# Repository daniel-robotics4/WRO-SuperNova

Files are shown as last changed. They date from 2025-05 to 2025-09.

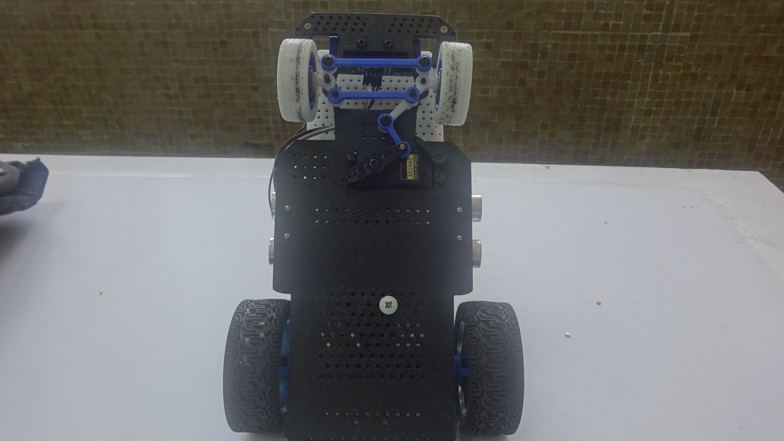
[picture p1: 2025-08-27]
v-photos/DELTA Bottom.JPG

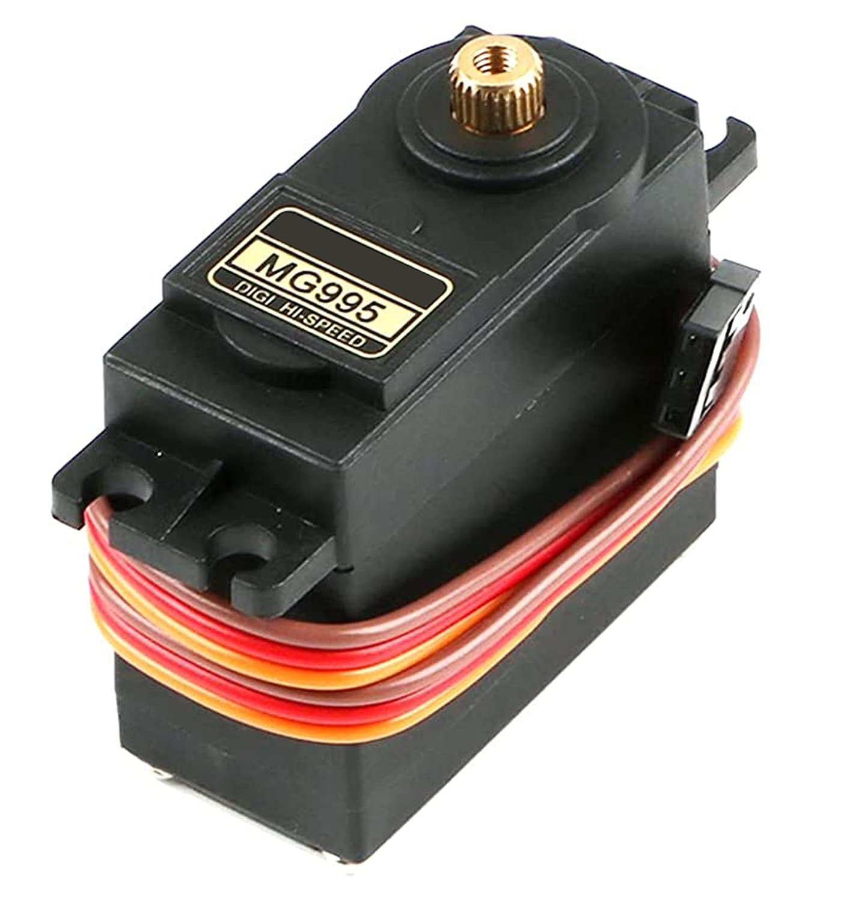
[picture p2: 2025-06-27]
other/Images of the readme/617BvnN0VJL._SL1500_.jpg

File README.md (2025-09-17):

 SuperNova 
====
supernova_final

This repository contains the documentation for the SuperNova team's robot for the 2025 World Robot Olympiad Future Engineers competition. the robot, was designed and built by a team of three students.

# Index

- [the Project](#the-project)
- [the Challenge](#the-challenge)
- [Photos of DELTA](#photos-of-delta)
- [Management](#management)
  - [Mobility Management](#mobility-management)
    - Motor DC 12v with encoder
    - Servo Motor MG995
    - Module l298n motor driver
  - [Power and Sense Management](#power-and-sense-management)
    - ESP32 DevKit v1
    - ESP32 expansion board
    - Ultrasonic sensors (hc-sr04)
    - 18650 Battery
    - Pixy Cam v2
    - Voltage regulator
- [Software/Code Documentation – CodigoDeluxe4_0.ino](#softwarecode-documentation--codigodeluxe40ino)
  - [Open challenge](#open-challenge)
    - [High-level summary](#high-level-summary)
    - [Includes and global objects](#includes-and-global-objects)
    - [Pin and constant definitions (as declared)](#pin-and-constant-definitions-as-declared)
    - [Pixy2 helper](#pixy2-helper)
    - [Ultrasonic functions](#ultrasonic-functions)
      - [filtrarUltrasonicos(NewPing &sonar)](#filtrarultrasonicosnewping--sonar)
      - [readUltrasonicSensors()](#readultrasonicsensors)
    - [Servo helper functions](#servo-helper-functions)
    - [Motor control functions](#motor-control-functions)
      - [setMotorDirection(bool forward)](#setmotordirectionbool-forward)
      - [stopMotor()](#stopmotor)
      - [MotorSpeed(bool direccion, int velocidad)](#motorspeedbool-direccion-int-velocidad)
    - [Encoder-based movement functions](#encoder-based-movement-functions)
      - [EncoderForward(int encoderTicks)](#encoderforwardint-encoderticks)
      - [EncoderBackward(int encoderTicks)](#encoderbackwardint-encoderticks)
    - [Turn routines (composed actions)](#turn-routines-composed-actions)
    - [Small correction routines](#small-correction-routines)
    - [backwardFinal()](#backwardfinal)
    - [setup()](#setup)
    - [loop() and finite-state machine (FSM)](#loop-and-finite-state-machine-fsm)
      - [START](#start)
      - [SENSE](#sense)
      - [RIGHT](#right)
      - [LEFT](#left)
      - [STRAIGHT](#straight)
      - [STOPPED](#stopped)
      - [default](#default)
    - [Variables involved in control flow](#variables-involved-in-control-flow)
    - [How the pieces interact at runtime (short narrative)](#how-the-pieces-interact-at-runtime-short-narrative)
- [Cost Report](#cost-report)
  - [Components](#components)
  - [3D Printing Costs](#3d-printing-costs)
  - [Other Parts Tested](#other-parts-tested)
  - [Tools and Equipment](#tools-and-equipment)
  - [Summary of Costs](#summary-of-costs)
- [WRO SuperNova — Complete Assembly and Wiring](#wro-supernova--complete-assembly-and-wiring)
  1. [Quick overview](#1--quick-overview)
  2. [BOM](#2--bill-of-materials)
  3. [Tools](#3--tools)
  4. [PLA printing — settings & guidance (complete)](#4--pla-printing--complete-settings--guidance)
  5. [Hole, insert & fastener strategy for PLA](#5--hole-insert--fastener-strategy-for-pla-complete)
  6. [Part-specific print & post-process notes](#6--part-specific-print--postprocess-notes)
  7. [Mechanical assembly — step-by-step](#7--mechanical-assembly--stepbystep)
  8. [Electrical wiring — pin-by-pin](#8--electrical-wiring--pin-by-pin-match-to-code)
  9. [Power, decoupling and protection](#9--power)
  10. [Software, calibration & commissioning](#10--software-calibration--commissioning)

## Contents of the repository
· `t-photos`:Includes 2 photos of the team (one official and one fun with all members). 

`v-photos`: Contains 6 photos of the vehicle (from all angles, top and bottom).  

`video` : Video.md file with link to a driving demonstration video. 

`schemes`: Schematic diagrams (JPEG, PNG or PDF) of the electromechanical components, illustrating the connection of electronic elements and motors. 

`src`: Control software code for all components programmed for the competition.

`models`: Files for models used by 3D printers, laser cutters and CNC machines to produce vehicle elements.

`other`: Additional files to understand how to prepare the vehicle for competition (SBC/SBM connection documentation, file upload, hardware specifications, etc.), old code and the images on the repository.

the Project
===
Our project consists of creating an automated land vehicle capable of navigating an environment marked by colored obstacles. the vehicle takes different paths depending on the color of the obstacle. We use an ESP32-based program (C++) that includes codes for the ultrasonic sensors (hc-sr04), which can detect objects at a predetermined distance. When an obstacle is detected, the sensors send a signal to the ESP32 circuit board, which then directs the vehicle’s movement system to turn det either clockwise or counterclockwise, as pre-established. Additionally, the vehicle is equipped with a camera module (Pixy v2) to detect colored obstacles and avoid them based on their color

the core of the system is based on the ESP32 v1 devkit microcontroller, which provides a versatile platform with sufficient input/output pins and processing capability to manage multiple sensors and actuators for basic robotics applications. the vehicle features a DC motor equipped with an encoder, allowing for precise feedback on wheel rotation to enable closed-loop speed and distance control. Four ultrasonic sensors are strategically mounted to the vehicle, giving comprehensive environmental awareness by measuring distances to obstacles in front and on both sides. A motor driver shield is used to manage power delivery and control signals to the motor, while a servomotor handles steering actuation. the chassis for this vehicle was custom-designed using 3D modeling software and subsequently fabricated with a 3D printer.

## the Challenge
Teams are challenged to create, assemble, and program a robotic car that can drive itself around a racetrack that is dynamically altered for every round. there are two primary objectives in the competition: finishing laps with randomized obstacles and pulling off a flawless parallel parking manoeuvre. Teams must incorporate cutting-edge robotics ideas with an emphasis on innovation and dependability, such as computer vision, sensor fusion, and kinematics.

This challenge emphasizes all aspects of the engineering process, including:

- Mobility Management: Developing efficient vehicle movement mechanisms.
- Obstacle Handling: Strategizing to detect and navigate traffic signs (red and green markers) within specified rules.
- Documentation: Showcasing engineering progress, design decisions, and open-source collaboration through a public GitHub repository.

## Photos of DELTA

| Front view | Back view | Left view | 
| --- |--- | --- |
| DELTA Front| DELTA Back| DELTA Left|

| Right view | Top view | Bottom view |
| --- | --- |--- |
|DELTA Right| DELTA Top |DELTA Bottom |

## Management

### Mobility Management

**Motor DC 12v with encoder:**
| Specifications: |
| ------------- |
| Voltage: 12V |
| Gear Ratio: 1:34 |
| Speed (at 12V): 126 RPM |
| Torque: 4.2 kg·cm |
| Weight: 86g |
| Encoder: Optical, 12 counts per revolution |
encoder2

the propulsion system relies on a DC motor paired with an encoder. the motor provides the mechanical force required to move the vehicle, while the encoder outputs two pulse signals (c!
hannels A and B) that indicate the rotation direction and speed by measuring the number of pulses per revolution.
We used these motors for their balance between power, efficiency, and cost, as well as their easy integration with common motor drivers like the L298N.

**Servo Motor MG995:**
| Specifications: |
| ------------- |
| Voltage: 4.8-6V |
| Torque: 9.4/11 kg/cm |
| Rotation: 180° ± 10°  |
617BvnN0VJL _SL1500_

A servomotor is integrated into the system to control steering. the servo receives PWM signals from a dedicated ESP32 pin, allowing precise angular positioning between 0° and 180°. the servo’s position is controlled programmatically to perform smooth and accurate movements.
We chose this servo for its precise position control, ease of use with Arduino libraries, and widespread availability, offering better accuracy and reliability than cheaper or less-documented servos.

**Module l298n motor driver:**
| Specifications: |
| ------------- |
| Power supply voltage: 5 to 35V  |
| Output current:  0-36mA |
| Can handle:  DC motors or stepper motors |
modulo-l298n-driver-control-motor-puente-h-arduino-0

the L298N is a robust dual H-bridge motor driver IC capable of controlling two DC motors simultaneously or one stepper motor. Each channel of the L298N can deliver up to 2A continuous current (with adequate heat dissipation) and operates within a voltage range of 5V to 35V, making it suitable for a wide range of motors.
This motor driver module interfaces easily with the ESP32 microcontroller, accepting PWM signals from the ESP32 for precise speed control and digital signals for direction control, enabling both forward and reverse movement. the L298N module also includes built-in protection mechanisms such as current sensing and thermal shutdown to safeguard the system during operation.
the L298N was selected for this project due to its ability to control two motors at once, its compatibility with the ESP32.

### Power and Sense Management

**ESP32 DevKit v1:**

|Specifications:|
| ------------ |
|Microcontroller: ESP32 |
|Flash memory: 4 Mb |
|SRAM: 520 Kb | 
|Frequency: 2.4 GHz to 2.5 GHz |
|Input voltage: 2.7 – 3.6V |
|Pins: 30 |
ModuloESP32-DEVKITV1-30pines-min_1_2048x2048

ESP32 DevKit V1:
the ESP32 DevKit V1 is a microcontroller board based on the ESP32 SoC, featuring a dual-core Tensilica processor running at up to 240 MHz. It offers integrated Wi-Fi and Bluetooth, multiple digital input/output pins, analog inputs, PWM outputs, a micro-USB connection, onboard voltage regulator, and reset/boot buttons. the ESP32 board runs the code that enables us to accomplish the challenge, processing sensor data to perform the required movements.

We selected the ESP32 DevKit V1 for its wireless connectivity, higher processing power, and compatibility with a wide range of sensors and actuators. Its user-friendly development environment, strong community support, and extensive documentation make it easier to implement complex robotics tasks compared to less-documented microcontroller boards.

**ESP32 Expansion Base board v1:**

|Specifications:|
| ------------ |
|Power supply: 5-12V|
|On-board Regulator : 5V~1A |
|SRAM: 520 Kb | 
|Frequency: 2.4 GHz to 2.5 GHz |
|Input voltage: 2.7 – 3.6V |
expansion board

the ESP32 Expansion Board V1 30P is an add-on board designed to extend the functionality of ESP32 development boards, featuring 30 accessible pins for easy connection to various peripherals. It provides organized access to multiple digital and analog inputs/outputs, power rails, and communication interfaces such as I2C, SPI, and UART. the expansion board simplifies prototyping by offering clearly labeled headers, additional power regulation options, and secure mounting for the ESP32 module, enabling robust connections for sensors, actuators, and external modules.

We selected the ESP32 Expansion Board V1 30P for its convenient pin access, stable power distribution, and compatibility with a broad range of hardware components. Its well-organized layout, ease of integration, and community support streamline the development of complex robotics solutions, making it preferable to less modular expansion boards or direct wiring, which can lead to unreliable connections and increased troubleshooting.

**Ultrasonic Sensor (hc-sr04):**
| Specifications: |
| ------------- |
| Accuracy:  ±3% |
| Measurement Range: 2 a 450 cm |
| Resolution:  0.3 cm |
| Input voltage: 5V  |
| Operating Current: 15mA |
Ultrasonic_Sensor

It is a sensor that uses ultrasonic sounds to detect the bounce time of sound from one side to the other. Using the ESP32 devkit v1 we can determine the distance based on the time it takes for the wave to return, performing the function of determining when there is a wall nearby, and thus making the corresponding turn.
This sensor was chosen for its accuracy, low cost, and readily available documentation, outperforming other more expensive or less reliable distance-sensing options.

**18650 Battery:**
| Specifications: |
| ------------- |
| Capacity: 3000 mAh |
| Voltage: 3.7 V |
| Discharge rate:  0.25C |
| Weight: 48 g (one battery) |
| Size: 18 mm diameter, 65 mm length |


we are going to use 3 of these li-ion batterys in parallel to power the vehicle, with an 18650 battery holder. This battery configuration provides a reliable and efficient power source for the robot’s electronics and actuators, supporting extended operation during competition or testing.

**PixyCam v2:**
| Specifications: |
| ------------- |
| Processor: NXP LPC4330 |
| Image sensor: Aptina MT9M114 |
| Resolution:1296×976  |
| Lens field-of-view: 80° horizontal, 40° vertical |
| Power consumption: 140mA |
| RAM: 264K bytes |
| Flash Memory: 2M bytes |
| Power input: 5V |
pixy-v21-camera-sensor

the camera is capable of detecting seven colors simultaneously and It is equipped with an internal processor, which lets us explore just the necessary information for the ESP32 to evade in the necessary way, depending on the obstacle colour.
 We selected this camera for its high-resolution image capture, easy interfacing with microcontrollers, and strong community support, providing superior performance and documentation compared to less common camera modules.

**Voltaje Regulator (Lm2596) :**
| Specifications: |
| ------------- |
| Input Voltage: 4V to 35V |
| Output Voltage:  1.23V to 37V |
| Energy eficiency : 80% |
voltage regulator

The module LM2596 is a regulator step down that can reduce de voltage of input to a lower voltage in output 

# Software/Code Documentation – `CodigoDeluxe4_0.ino`

This document describes the structure, logic, and key functions of the file: `src/CodigoDeluxe4_0.ino` in the WRO-SuperNova project.

---
# Open challenge 

## High-level summary
Firmware for an ESP32-based robot that:
- Reads four ultrasonic sensors (front, right, left, rear) using the NewPing library.
- Uses an ESP32 encoder for distance/tick measurements.
- Controls a DC motor through two direction pins and an enable pin (ENB).
- Uses a single servo for steering with three preset positions (left, center, right).
- Implements a finite-state machine to drive, sense obstacles, decide turns, execute turns using encoder distances, and count laps.

---

## Includes and global objects
- Libraries:
  - `Arduino.h`, `WiFi.h`, `Pixy2.h`, `NewPing.h`, `ESP32Encoder.h`, `ESP32Servo.h`.
- Global peripheral objects:
  - `Pixy2 pixy;`
  - `NewPing sonarRight(TRIGGER_PIN_RIGHT, ECHO_PIN_RIGHT, MAX_DISTANCE);` — right ultrasonic
  - `NewPing sonarLeft(...)` — left ultrasonic
  - `NewPing sonarFront(...)` — front ultrasonic
  - `NewPing sonarRear(...)` — rear ultrasonic
  - `Servo servo;` — steering servo
  - `ESP32Encoder encoder(true);` — encoder instance (quadrature/direction enabled)

---

## Pin and constant definitions (as declared)
- Motor:
  - DIR_PIN_A = 16
  - DIR_PIN_B = 17
  - pinENB = 5
- Ultrasonics:
  - Right: TRIGGER 33, ECHO 25
  - Left:  TRIGGER 27, ECHO 26
  - Front: TRIGGER 12, ECHO 14
  - Rear:  TRIGGER 22, ECHO 23
- Servo pin: 2
- Distances, thresholds and tuning variables:
  - MAX_DISTANCE = 300
  - servoL = 115, servoC = 80, servoR = 50
  - frontObject = 90
  - cantMuestras = 5 (samples per ultrasonic sensor read)
  - DELAY_ULTRASONICOS = 10 (ms)
  - wallfence = 20
  - laps = 0
  - sense = 0 (direction chosen during sensing: 1 or 2)
  - maximumCorrections = 0

---

## Pixy2 helper
- `getSignatureColorName(int signature)`
  - Returns a human-readable name for a Pixy signature id.
  - Cases: `1 -> "Verde"`, `2 -> "Rojo"`, default -> `"Desconocido"`.
- (There are commented-out helper functions that format Pixy block data as HTML; they call `pixy.ccc.getBlocks()` and iterate `pixy.ccc.blocks` to extract signature, x/y/width/height.)

---

## Ultrasonic functions

### filtrarUltrasonicos(NewPing &sonar)
- Purpose: take multiple readings from a single NewPing sonar and return a filtered average distance in cm.
- Behavior:
  - Performs `cantMuestras` readings using `sonar.ping_cm()`.
  - Treats `0` returned by `ping_cm()` as `MAX_DISTANCE`.
  - Keeps running `sum`, tracks `minVal` and `maxVal`, and counts samples (`validCount`).
  - After sampling, subtracts `minVal` and `maxVal` from `sum` (trim one min and one max) and divides by `validCount - 2` (if `validCount >= 3`) or `validCount` otherwise.
  - Returns the computed average as `unsigned int`.
- Notes on outputs: returns a value in cm bounded by `MAX_DISTANCE`.

### readUltrasonicSensors()
- Purpose: update global distances for all four ultrasonic sensors.
- Behavior: calls `filtrarUltrasonicos()` for each sonar and stores results in:
  - `distanceFront`, `distanceRight`, `distanceLeft`, `distanceRear`.
- After reading, any zero distances are set to `MAX_DISTANCE` (safeguard).

---

## Servo helper functions
- `servoRigth()` — write servo angle `servoR` (steer right) and short `delay(15)`.
- `servoLeft()` — write servo angle `servoL` (steer left) and short `delay(15)`.
- `servoCenter()` — write servo angle `servoC` (center steering) and short `delay(15)`.

These functions position the steering servo to one of three predefined angles.

---

## Motor control functions

### setMotorDirection(bool forward)
- Sets motor direction pins for forward or backward motion:
  - If `forward == true`: DIR_PIN_A = LOW, DIR_PIN_B = HIGH.
  - Else: DIR_PIN_A = HIGH, DIR_PIN_B = LOW.

### stopMotor()
- Stops the motor by setting DIR_PIN_A = LOW, DIR_PIN_B = LOW and pinENB = LOW.

### MotorSpeed(bool direccion, int velocidad)
- Calls `setMotorDirection(direccion)` to choose direction.
- Writes `velocidad` to `pinENB` using `digitalWrite(pinENB, velocidad)`.
- Intended to control motor speed and direction together.

---

## Encoder-based movement functions

### EncoderForward(int encoderTicks)
- Purpose: move forward until the encoder count reaches `encoderTicks`.
- Behavior:
  - Calls `encoder.clearCount()` to reset the encoder count.
  - While `encoder.getCount() < encoderTicks`:
    - Calls `MotorSpeed(true, 150)` to move forward.
    - Delays 10 ms inside loop.
  - Calls `stopMotor()` and `encoder.clearCount()` at the end.

### EncoderBackward(int encoderTicks)
- Purpose: move backward until the encoder count goes beyond `encoderTicks`.
- Behavior:
  - Calls `encoder.clearCount()`.
  - While `encoder.getCount() > encoderTicks`:
    - Calls `MotorSpeed(false, 150)` to move backward.
    - Delays 10 ms inside loop.
  - Calls `stopMotor()` and `encoder.clearCount()` at the end.

Notes:
- These functions use the encoder reading to control distances moved by repeated on/off motor commands until the encoder target is reached.

---

## Turn routines (composed actions)
Each routine uses the encoder move functions and servo to perform a turn maneuver.

- `Lbig()`:
  - Calls `EncoderBackward(-700)` (back up),
  - Calls `servoLeft()` (steer left),
  - Calls `EncoderForward(1300)` (move forward the turn distance),
  - Calls `servoCenter()` (re-center).

- `Lsmall()`:
  - Calls `EncoderBackward(-650)`,
  - `servoLeft()`,
  - `EncoderForward(1300)`,
  - `servoCenter()`.

- `Rbig()`:
  - Calls `EncoderBackward(-700)`,
  - `servoRigth()` (steer right),
  - `EncoderForward(1300)`,
  - `servoCenter()`.

- `Rsmall()`:
  - Calls `EncoderBackward(-650)`,
  - `servoRigth()`,
  - `EncoderForward(1300)`,
  - `servoCenter()`.

These routines perform: back up slightly, set steering to turn direction, move forward a fixed encoder distance to complete the turn, then re-center the servo.

---

## Small correction routines
- `correctionL()`:
  - Set servo to left,
  - Call `MotorSpeed(true, 120)` to move forward briefly,
  - `delay(200)`,
  - `servoCenter()` and `delay(15)`.

- `correctionR()`:
  - Set servo to right,
  - `MotorSpeed(true, 120)`,
  - `delay(200)`,
  - `servoCenter()` and `delay(15)`.

These move the robot slightly forward while steering to perform small lateral corrections.

---

## backwardFinal()
- Calls `Lbig()` if `sense == 1`.
- Calls `Rbig()` if `sense == 2`.
- Used as a final backup-and-turn routine when stopping.

---

## setup()
- Initializes Serial at 115200.
- Configures motor pins DIR_PIN_A, DIR_PIN_B, pinENB as OUTPUT.
- Attaches servo on `servoPin` with pulse width range 500–2500 µs.
- Initializes Pixy2: `pixy.init()`.
- Configures encoder:
  - Enables internal pull-ups: `ESP32Encoder::useInternalWeakPullResistors = puType::up`.
  - Attaches encoder pins with `encoder.attachSingleEdge(4, 5)`.
  - Clears encoder count `encoder.clearCount()`.
- Initializes `lastStateChangeTime = millis()` (used for potential state timing).

---

## loop() and finite-state machine (FSM)
`loop()` repeatedly:
- Calls `readUltrasonicSensors()` to update distanceFront, distanceLeft, distanceRight, distanceRear.
- Updates `encoderTicks = encoder.getCount()`.
- Uses `switch(currentState)` to run the FSM. States:

### START
- Centers the servo.
- Reads ultrasonic sensors.
- Sets `sense = 0`.
- Calls `MotorSpeed(true, 200)` to move forward.
- If `distanceFront < frontObject` and `distanceFront != MAX_DISTANCE` and `sense == 0`:
  - Calls `stopMotor()`.
  - Sets `currentState = SENSE`.

### SENSE
- Decides turning direction by comparing lateral distances:
  - If `distanceLeft < distanceRight`:
    - Sets `sense = 2` (right) and `currentState = RIGHT`.
  - If `distanceRight < distanceLeft`:
    - Sets `sense = 1` (left) and `currentState = LEFT`.

### RIGHT
- If `laps < 11`:
  - If `distanceLeft < 70` and `distanceLeft > 0`:
    - `laps += 1; Rbig(); readUltrasonicSensors(); maximumCorrections = 0; currentState = STRAIGHT;`
  - Else if `70 < distanceLeft < 100`:
    - `laps += 1; Rsmall(); readUltrasonicSensors(); maximumCorrections = 0; currentState = STRAIGHT;`
- Else if `laps >= 11`:
  - `currentState = STOPPED`.

### LEFT
- Symmetric behavior to RIGHT but uses `distanceRight` for decisions:
  - If `distanceRight < 70` and `distanceRight > 0` => `Lbig()` etc.
  - If `70 < distanceRight < 100` => `Lsmall()` etc.
  - If `laps >= 11` => `currentState = STOPPED`.

### STRAIGHT
- Calls `MotorSpeed(true, 70)` to drive forward at a slower speed.
- Calls `readUltrasonicSensors()` then:
  - If `distanceFront < frontObject` and `sense == 1` and `distanceFront > 50`:
    - `currentState = LEFT`.
  - If `distanceFront < frontObject` and `sense == 2` and `distanceFront > 50`:
    - `currentState = RIGHT`.
  - If `distanceFront < 10`:
    - Decrements `laps`, moves backward for a short fixed time (`MotorSpeed(false, 200)` + `delay(1500)`), then stops motor.
- Lateral corrections within STRAIGHT:
  - If `distanceLeft < wallfence` and `maximumCorrections < 2`: increment `maximumCorrections` and call `correctionR()`.
  - If `distanceRight < wallfence` and `maximumCorrections < 2`: increment `maximumCorrections` and call `correctionL()`.

### STOPPED
- Calls `backwardFinal()` (final backup & turn depending on `sense`).
- Calls `stopMotor()`.
- `delay(50000)` to remain stopped for a period.

### default
- Sets `currentState = STRAIGHT`.

---

## Variables involved in control flow
- `currentState` (enum CarState): `START`, `STOPPED`, `SENSE`, `RIGHT`, `LEFT`, `STRAIGHT`.
- `sense`: direction decision (1 = left, 2 = right, 0 = none).
- `laps`: increments each time a corner/turn is executed; used to limit runs.
- `maximumCorrections`: counter for lateral corrections applied while moving straight.

---

## How the pieces interact at runtime (short narrative)
- The robot begins in `START`, moves forward, and monitors the front ultrasonic sensor.
- When an obstacle is detected within `frontObject`, it transitions to `SENSE` and compares left/right distances to choose a turn direction (`sense`).
- It executes the chosen turn (big or small) using encoder-based forward/backward moves combined with steering via servo.
- After turning it enters `STRAIGHT` to follow the corridor, apply lateral corrections, and watch for the next obstacle to repeat the cycle.
- `laps` is incremented on each corner; when a target number of laps is reached the FSM transitions to `STOPPED` and performs a final backup-and-turn before stopping.

---

# Close challenge 

## 1 — High-level summary
This sketch runs on an ESP32 and coordinates a Pixy2 camera, four ultrasonic sensors (NewPing), a steering servo, an encoder, and a DC motor controlled by an H-bridge. The program implements a finite-state machine to search for colored blocks (green/red) using Pixy2 and execute preprogrammed maneuvers when colors are detected.

Main flow: START → WALL → SEARCH → (GREEN or RED) → back to SEARCH or WALL. Flags `G` and `R` remember whether a maneuver for green or red has already been executed.

---

## 2 — Pin mapping
- Motor:
  - DIR_PIN_A = GPIO16
  - DIR_PIN_B = GPIO17
  - pinENB = GPIO32 (H-bridge enable / speed)
- Servo:
  - servoPin = GPIO2
- Ultrasonic sensors (NewPing):
  - Right TRIG / ECHO = GPIO33 / GPIO25
  - Left TRIG / ECHO = GPIO27 / GPIO26
  - Front TRIG / ECHO = GPIO13 / GPIO14
  - Rear TRIG / ECHO = GPIO21 / GPIO34
- Encoder:
  - encoder.attachSingleEdge(4, 22) → channel A GPIO4, channel B GPIO22
- Pixy2:
  - object `pixy` used; blocks retrieved with `pixy.ccc.getBlocks()` and read via `pixy.ccc.blocks[]`

---

## 3 — Key variables and constants
- Servo angles: `servoL = 115`, `servoC = 80`, `servoR = 50`
- Ultrasonic parameters:
  - `MAX_DISTANCE = 300` cm
  - `cantMuestras = 5` samples per sensor
  - `DELAY_ULTRASONICOS = 10` ms between pings
  - `wallfence = 30` cm (distance considered "close" to a wall)
  - `frontObject = 90` (front threshold referenced in other sketches)
- Motion/encoder:
  - `ppr = 1400` pulses per revolution (not directly used here)
  - `laps`, `diameter` (context variables, not central here)
- Color flags:
  - `G` and `R` are 0/1 flags tracking green/red maneuvers
- `sense` determines preferred turn direction during the WALL routine
- `pixy.ccc.numBlocks` contains the number of color blocks detected by Pixy

---

## 4 — Main objects
- `Pixy2 pixy` — camera block detection (color signatures)
- `NewPing sonarRight/Left/Front/Rear` — ultrasonic sensors
- `ESP32Encoder encoder(true)` — quadrature encoder counter
- `Servo servo` — steering servo

---

## 5 — Important functions (what they do)

### filtrarUltrasonicos(NewPing &sonar)
- Takes `cantMuestras` readings with `sonar.ping_cm()`.
- Replaces 0 with `MAX_DISTANCE`.
- Sums values, discards min and max (if enough samples), and returns the averaged result.
- Purpose: reduce spurious readings / outliers.

### readUltrasonicSensors()
- Calls `filtrarUltrasonicos()` for each sensor and sets `distanceFront/Right/Left/Rear`.
- Ensures that a returned 0 is converted to `MAX_DISTANCE`.

### servoRight(), servoLeft(), servoCenter()
- Move the servo to preconfigured angles and wait 15 ms.

### setMotorDirection(bool forward), stopMotor(), MotorSpeed(bool direccion, int velocidad)
- `setMotorDirection` sets DIR pins for forward/backward.
- `stopMotor` sets both DIR pins LOW and `pinENB` LOW.
- `MotorSpeed` sets direction and calls `analogWrite(pinENB, velocidad)` to control speed.
  - Note: `analogWrite` is not the standard Arduino API on the ESP32 core — LEDC (ledcSetup/ledcAttachPin/ledcWrite) is recommended.

### EncoderForward(int encoderTicks), EncoderBackward(int encoderTicks)
- Clear encoder count, then loop while encoder count hasn't reached target, commanding MotorSpeed inside the loop and delaying.
- After reaching target, call stopMotor() and clear encoder count.
- These functions are blocking and currently have no timeout safeguards.

---

## 6 — State machine (detailed)

### START
- Centers servo, sets `sense = 1`, and transitions to `WALL`.
- Acts as a simple initialization step and chooses a default turning sense (right).

### WALL
- Moves forward with `MotorSpeed(true, 200)` for 2 seconds, then stops.
- Based on `sense`:
  - If `sense == 1`: steer right, reverse for 2 seconds, center servo, `EncoderForward(300)`, go to `SEARCH`.
  - If `sense == 2`: same but mirrored (left).
- Purpose: reposition the robot away from a wall and get into a search posture.
- Note: there is commented code that would choose `sense` based on left vs right distances; currently `sense` is forced in START.

### SEARCH
- Iterates over `pixy.ccc.numBlocks` and:
  - If `m_signature == 1` → set state to `GREEN`.
  - If `m_signature == 2` → set state to `RED`.
  - Else (inside the for) it calls `MotorSpeed(true, 200)` and delays 200 ms.
- Issue: If `pixy.ccc.numBlocks == 0`, the for-loop does not run and the robot will not advance. The intended behavior probably is: if no blocks detected, advance; otherwise process blocks. The current placement of MotorSpeed inside the `else` of the for is problematic.

### GREEN
- Behavior depends on flags `R` and `G`:
  - If `R == 1`: sequence Left → forward 400, Right → forward 900, Center → forward 100; set `G = 0`, return to `SEARCH`.
  - If `(G == 0) && (R == 0)`: Left → forward 700, Right → forward 700, Center → forward 100; set `G = 1`, return to `SEARCH`.
  - Else if `G == 1`: move slowly `MotorSpeed(true, 30)`; if `distanceFront < 20` → set `G = 0`, go to `WALL`.
- Purpose: first detection triggers a larger exploratory maneuver (marking `G = 1`), subsequent detections switch to slow advance until a frontal obstacle is detected.

### RED
- Symmetric to GREEN but using the `R` flag:
  - If `G == 1`: perform a maneuver, clear `G = 0`, return to `SEARCH`.
  - If `(R == 0) && (G == 0)`: perform a maneuver, set `R = 1`, return to `SEARCH`.
  - If `R == 1`: move slowly; if `distanceFront < 20` then `R = 0`, transition to `WALL`.

### STOPPED
- Present in the enum but not used.

---

---

# Cost Report
## Components
Component	Quantity	Cost per Unit ($)	Total ($)
| Componets | Component	Quantity  | Cost per Unit ($) | Total ($) |
| --- | --- |--- |--- |
| Motor DC GS20179-09 | 1 | 20.79 | 20.79 |
| Servo Motor MG995 | 1 | 3.71 | 3.71 |
| Module l298n motor driver | 1 | 4.99 | 4.99 |
| ESP32 DevKit v1 | 1 | 15.99 | 15.99 |
| ESP32 expansion board | 9.99 | 9.99 |
| Ultrasonic sensors (hc-sr04) | 4 | 4.99 | 15.96 |
| EBL 18650 Battery 3.7v 3300mha | 3 | 5.49 | 16.47 |
| PixyCam v2 | 1 | 69.90 | 69.90 | 
| Voltaje Regulator (Lm2596) | 1 | 4.52 | 4.52 | 
| Wheels of 2.559 | 2 | 4.99 | 9.98 | 
| 18650 3 battery holder | 1 | 1.99 | 1.99 |
| DuPont cable jumper | 1 kit | 7.99 | 7.99 |

**Total for Components: 182.28$**

## 3D Printing Costs
Filament Used:
Prototypes: 1.5 kg of PLA filament
Final Parts: 250g of PLA filament
PLA Filament Cost: 25.00 $  per 1kg
| Filament Use | Weight (g)	| Cost ($) |
| --- | --- | --- |
| Prototypes | 1,500 | 45.00 | 
| Final Parts	| 250 | 7.45 |

**Total for 3D Printing: 52.45$**

## Other Parts Tested
**Approximate Cost for Additional Parts Tested: 472.00$**
## Tools and Equipment
| Tool | Cost ($) |
| ---- | ---|
| Bambu Lab A1 mini 3D Printer | 299.00 |
| Soldering iron | 11.99 |
| Multimeter | 18.00 |
| Miscellaneous Tools | 39.00 |

**Total for Tools and Equipment: 367.00$**

## Summary of Costs
| Category | Total ($) | 
| --- | --- |
| Components | 174.29 |
| 3D Printing | 52.45 |
| Other Parts Tested | 472.00 |
| Tools and Equipment | 367.00 |
| Shipping Approximation | 10.00 |

**Grand Total: 1.082,99$**

*Note: Costs are approximate and based on current exchange rates and market prices.*

# WRO SuperNova — Complete Assembly and Wiring

This is the single, canonical assembly guide for DELTA. It covers everything from printing settings to mechanical assembly, wiring to the corrected firmware (ENB → GPIO13 PWM), safety, commissioning and troubleshooting — all in one place so you can follow it end-to-end.

Use the repo images for reference during assembly:
- other/Images of the readme/ModuloESP32-DEVKITV1-30pines-min_1_2048x2048.jpg
- other/Images of the readme/Base expansora para ESP32.jpg
- other/Images of the readme/Ultrasonic_Sensor.jpg
- other/Images of the readme/pixy-v21-camera-sensor.jpg
- other/Images of the readme/voltage regulator.jpg
- v-photos/ The DELTA photos for mechanical orientation
- schemes/ use the schemes for cable orientation 

Repository firmware this guide matches:
- CodigoDeluxe4_1.ino

---

Table of contents
1. Quick overview
2. BOM 
3. Tools
4. PLA printing — settings & guidance (complete)
5. Hole, insert & fastener strategy for PLA
6. Part-specific print & post‑process notes
7. Mechanical assembly — step‑by‑step (with wiring cues)
8. Electrical wiring — pin-by-pin
9. Power, decoupling and protection
10. Software, calibration & commissioning

---

1 — Quick overview
This guide assumes you will print almost all robot mechanical parts in PLA. PLA works well: good dimensional accuracy, stiff parts, and easy printing. This guide addresses PLA limitations (heat sensitivity, reduced screw-hold longevity) and gives methods to make a reliable robot while staying .

Firmware/pin reference:
- Motor DIR A → GPIO16
- Motor DIR B → GPIO17
- Motor EN (PWM) → GPIO13 
- Servo signal → GPIO2 (MG995)
- Encoder A/B → GPIO4 / GPIO5
- Ultrasonics:
  - Front TRIG/ECHO → GPIO12 / GPIO14
  - Right TRIG/ECHO → GPIO33 / GPIO25
  - Left TRIG/ECHO → GPIO27 / GPIO26
  - Rear TRIG/ECHO → GPIO22 / GPIO23
- Pixy2 → SPI recommended (3.3V Vcc); connect per Pixy docs

---

2 — Bill of Materials 
Mechanical
- Robot CarDC V4 chasis .stl — bottom chassis
- Chasis superior V2.stl — top cover
- Direccionales Robot Chasis V4.stl — steering mounts / knuckles
- MG995.stl (horn/bracket) or use the servo-supplied horn
- Ruedas V2.stl

Electronics
- ESP32 DevKit (30-pin)
- Motor driver L298n
- expansion board v1 for ESP32
- DC motor with encoder and wheels
- MG995 or similar servo
- Pixy2 camera module
- 4 × HC-SR04 ultrasonic sensors 
- Power: 18650 3000mh x3
- Wiring: DuPont jumper wires
  
Consumables & fasteners
- M3 machine screws (assorted lengths) + M3 nuts
- Zip‑ties, foam tape, cable clips

---

3 — Tools
- 3D printer (FDM) configured for PLA
- Small screwdriver set (PH0/PH1), hex keys
- Soldering iron + shrink tubing
- Multimeter
- Wire stripper/crimper, pliers
- Drill or reamer (3.0–3.2 mm) for hole finishing
- Heat gun/hot air or soldering iron for low-temp insert installation (use with care)
- Calipers for dimensional checks

---

4 — PLA printing — complete settings & guidance

Printer nozzle & bed
- Nozzle: 0.4 mm
- Bed: PEI, glass or taped bed works fine
- Nozzle temp: 200–210 °C (start 205 °C; tune by filament)
- Bed temp: 55–60 °C
- Fan: 100% after first 2–3 layers

Layer & perimeters
- Layer height: 0.16–0.20 mm (0.12 mm for small high-detail pivots)
- Perimeters: 3–4 (4 recommended for chassis and load zones)
- Top/bottom layers: 6

Infill
- Chassis & load-bearing parts: 35–40% gyroid or grid
- Brackets/covers: 15–25%
- Pivot/knuckle areas: 30–40%

Speeds & retraction
- Print speed: 40–50 mm/s
- Perimeter speed: 30–40 mm/s for stronger walls
- Retraction: Bowden 4–6 mm / Direct 0.8–1.2 mm; retraction speed 25–40 mm/s

Adhesion & supports
- Brim: 3–8 mm for large chassis parts
- Supports: tree supports for overhangs; minimize contact with cosmetic surfaces
- First layer: 20–25 mm/s, slightly higher extrusion multiplier if needed

Slicer tuning tips
- Use 4 perimeters for screw bosses; enable “pause after layer” if you want to embed nuts mid-print.
- Turn on “Z hop” only if needed; it can reduce small scuffs.
- Enable “coast at end” and “retraction in wipe” if stringing appears.

Cooling & warping
- PLA benefits from active cooling; ensure 100% fan once layers are stable.
- For long prints, avoid drafts or sudden ambient temp changes.

---

5 — Hole, insert & fastener strategy for PLA (complete)

PLA characteristics
- Stiff and dimensionally accurate, but more brittle and less heat-resistant than PETG.
- Repeated screwing into raw PLA will wear threads.

Recommended fastening approaches

Hole prep
- Print holes slightly undersized.
- Ream or drill to 3.0–3.2 mm for M3 clearance if using machine screws with nuts.
- For screws threading into PLA, pilot holes 2.6–2.8 mm are good for M3 self-tapping screws.

---

6 — Part-specific print & post‑process notes

A) Main chassis — Robot CarDC V4 chasis .stl
- Orientation: flat on the bed — largest surface down.
- Settings: 0.16–0.20 mm layer, 4 perimeters, 40% infill, brim 5–8 mm.
- Post: ream screw holes, remove any internal supports, chamfer screw entry slightly for easier insertion.

B) Top layer — Chasis superior V2.stl
- Orientation: as modeled for correct standoffs up.
- Settings: 0.16–0.20 mm layer, 3 perimeters, 20% infill.
- Post: test-fit standoffs and ESP32/devkit.

C) Direccionales (steering) — Direccionales Robot Chasis V4.stl
- Orientation: pivot holes vertical (hole axis along Z) for best circularity.
- Settings: 0.12–0.16 mm layer for pivot detail, 4 perimeters around pivots, 30% infill.
- Post: sand pivot bores lightly; test-fit bearings/bushings.

D) Servo horn & bracket — MG995.stl
- Orientation: horn flat on bed.
- Settings: 0.12–0.16 mm layer, 4 perimeters, 30% infill.
- Post: test fit on servo spline; if tight, sand minimal.

---

7 — Mechanical assembly — step‑by‑step

Preparation (before fastening)
- Clean all prints, deburr, ream holes as needed, and gather hardware and electronics.
- Label wires (TRIG/ECHO, motor, servo) with tape for easy routing.

Assembly Steps
1) Install the motor into bottom chassis
   - Mount motor in motor mount provided; use M3 screws with nuts. Keep motor wire exit toward the side for short routing, add the smaller gear into the motor.

2) Mount wheel hubs and steering module
   - Place the inside bearing, then the bar and the bigger gear and the outside bearing, mount the wheels and the use the bottom photo of delta fro better guidance for the steering module

3) Mount motor driver 
   - Place motor driver close to motor to minimize VMOT wiring.

4) Mount ESP32 DevKit
   - Place ESP32 on the expansion board/expansion hat in the designated place in the top layer.
   - Secure with M2.5/M3 screws and nuts; use a captive nut if possible.

5) Mount servo (MG995)
   - Place servo in its bracket, secure with M3 screws.
   - Attach horn matching steering arm and center servo before final tightening.

6) Install ultrasonic sensors
   - Insert HC‑SR04 modules into their cutouts with front facing outward.
   - Secure with screws or double-sided tape; ensure sensor face is unobstructed.

7) Mount Pixy2 camera
   - Attach Pixy2 on front bracket; route its cable toward the ESP32 hat area.
   - the Pixy needs a designated regulator for the 5V

8) Connect encoder wires
   - Route encoder A/B to GPIO4/GPIO5; keep wires short and twisted.

9) Connect servo and sensors
   - Route servo signal to GPIO2; servo Vcc to dedicated 5–6V supply (do not power servo from weak 5V regulators).

10) Place top layer & fasten
   - attach the top layer, secure with screws (.

11) Cable routing & strain relief
   - Use zip ties; ensure no wires touch moving parts.
   - Keep high-current motor wires separate from sensor wires.

---

8 — Electrical wiring — pin-by-pin (match to code)

Pin mapping:
- Motor DIR A (IN1) ← GPIO16
- Motor DIR B (IN2) ← GPIO17
- Motor EN (PWM ENB) ← GPIO13 (LEDC ch0)
- Servo signal ← GPIO2 (MG995)
- Encoder A ← GPIO4
- Encoder B ← GPIO5
- HC-SR04 Front: TRIG → GPIO12, ECHO → GPIO14 (ECHO level-shifted)
- HC-SR04 Right: TRIG → GPIO33, ECHO → GPIO25 (ECHO level-shifted)
- HC-SR04 Left: TRIG → GPIO27, ECHO → GPIO26 (ECHO level-shifted)
- HC-SR04 Rear: TRIG → GPIO22, ECHO → GPIO23 (ECHO level-shifted)
- Pixy2: SPI recommended (MOSI/MISO/SCK/CS) — Pixy Vcc → 3.3V, GND → common GND

Wiring rules
- All grounds must be common: ESP32 GND, motor driver GND, servo GND, sensor GND.
- Use JST connectors for sensors & servo where practical to make removal easy.

Motor driver wiring
- VMOT (+) ← motor battery positive 
- VMOT GND ← motor battery negative
- IN1 ← GPIO16; IN2 ← GPIO17; EN ← GPIO13 (PWM)
- OUTA/OUTB ← motor terminals

---

9 — Power

Power rails
- 3 3.7v 18650 batteries in parallel going to each regulator for its designated components 

---

10 — Software, calibration & commissioning

Firmware
- Use the provided `CodigoDeluxe4_1.ino`.
- Ensure you uploaded the corrected sketch (ENB on GPIO13).

Note: To upload code from the Arduino IDE to an ESP32, first ensure the ESP32 board package is installed via the Boards Manager within the Arduino IDE.
 Select the correct ESP32 board model from the Tools > Board menu and choose the appropriate COM port under Tools > Port.
 For boards that do not enter flashing mode automatically, press and hold the BOOT button on the ESP32 while clicking the Upload button in the Arduino IDE; release the BOOT button once the upload process starts.
 If the upload fails with a timeout error, try pressing the on-board RST or EN button when the IDE shows "Connecting..." in the output console.
 After a successful upload, press the EN button to restart the ESP32 and run the new code.

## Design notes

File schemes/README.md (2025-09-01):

Electromechanical diagrams
====

DELTA Final electric diagram

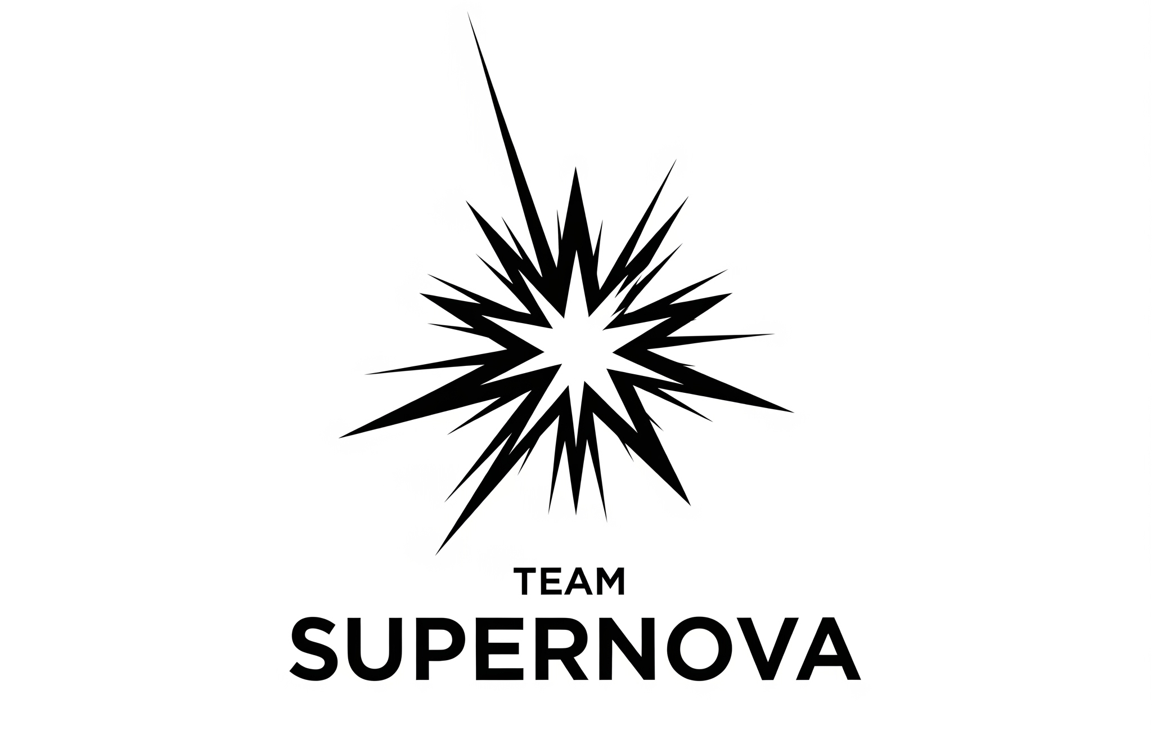
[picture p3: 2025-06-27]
other/Images of the readme/supernova_final.png

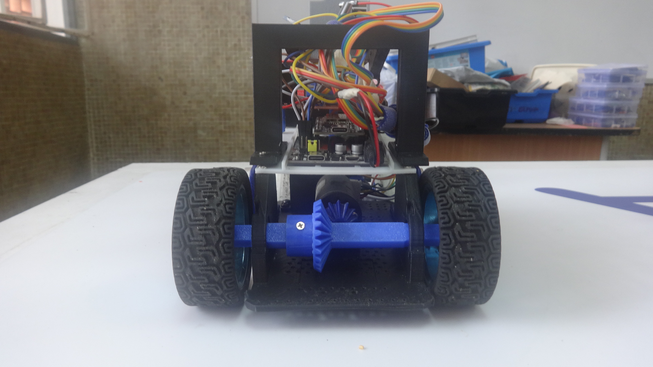
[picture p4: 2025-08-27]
v-photos/DELTA Back.JPG

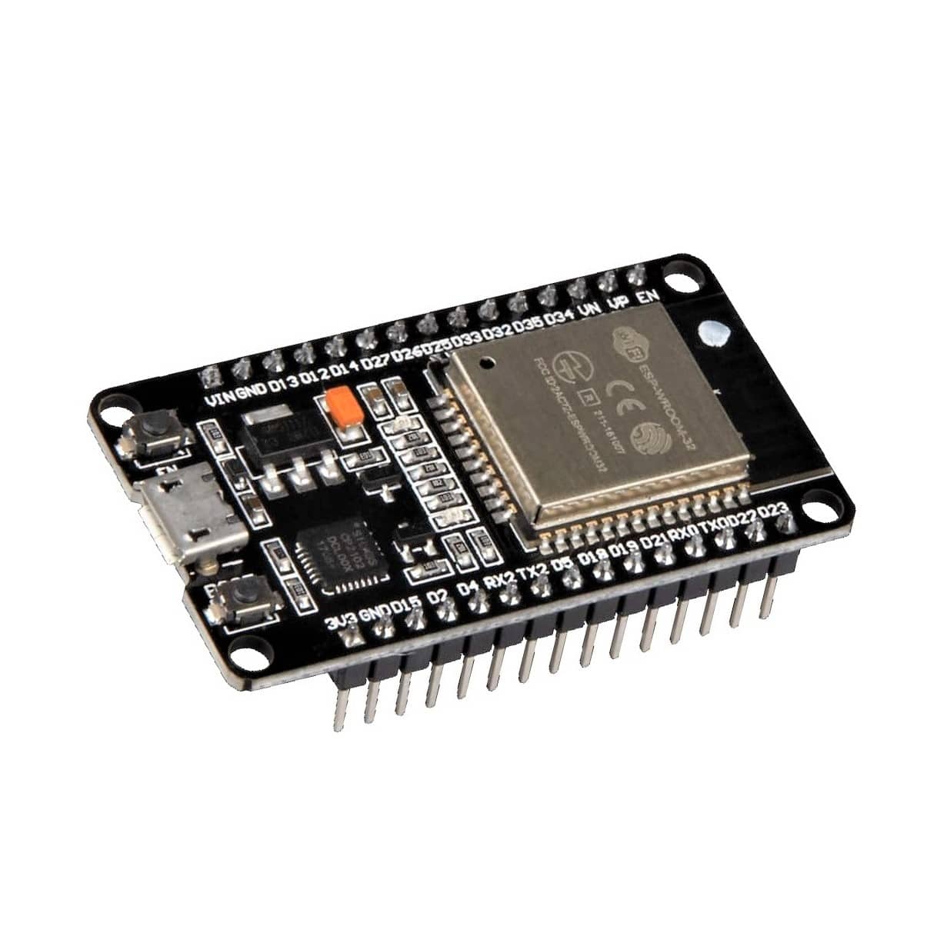
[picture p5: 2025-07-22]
other/Images of the readme/ModuloESP32-DEVKITV1-30pines-min_1_2048x2048.jpg

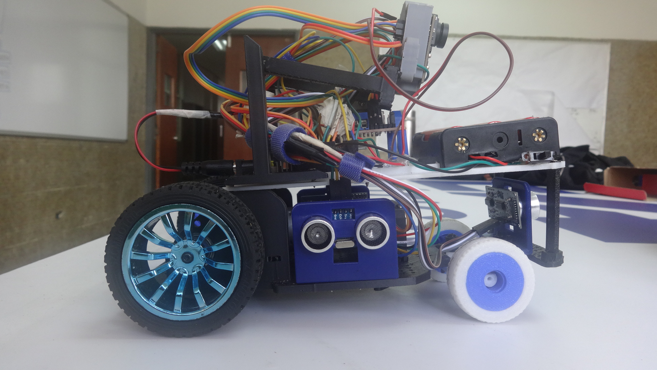
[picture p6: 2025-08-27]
v-photos/DELTA Right.JPG

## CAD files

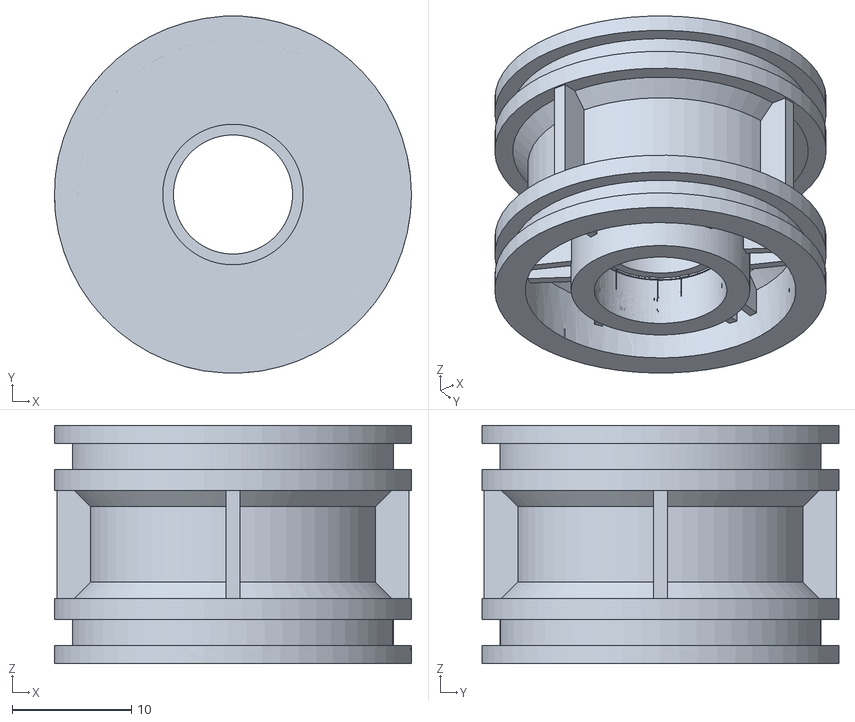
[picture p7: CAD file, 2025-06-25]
models/Rueda v2.stl
30.0 x 30.0 x 20.0

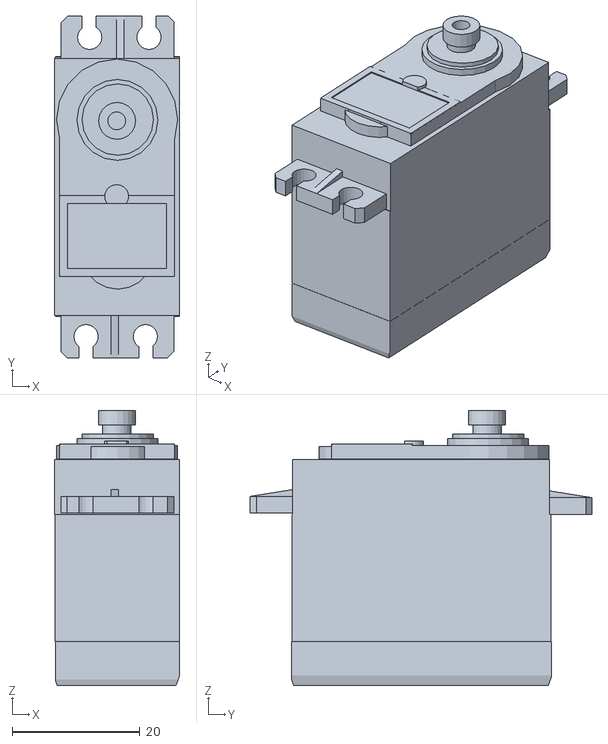
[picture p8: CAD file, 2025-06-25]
models/MG995.stl
19.6 x 53.6 x 43.2

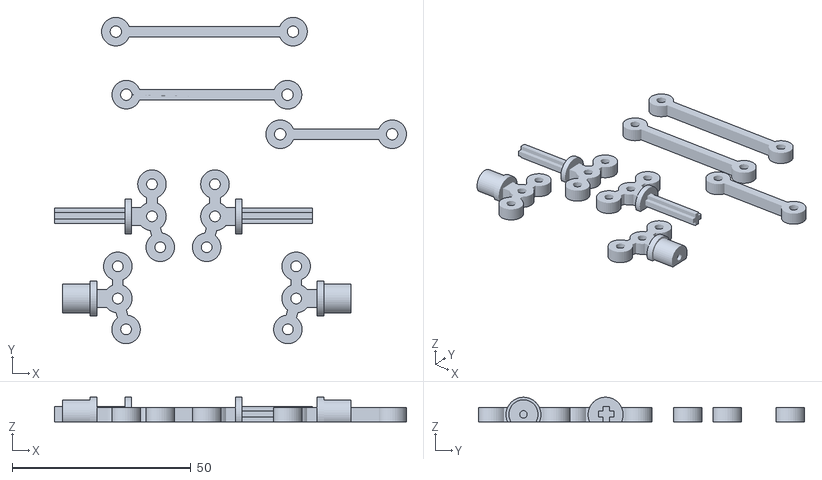
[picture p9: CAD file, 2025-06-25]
models/Direccionales Robot Chasis V4.stl
98.4 x 91.2 x 6.91

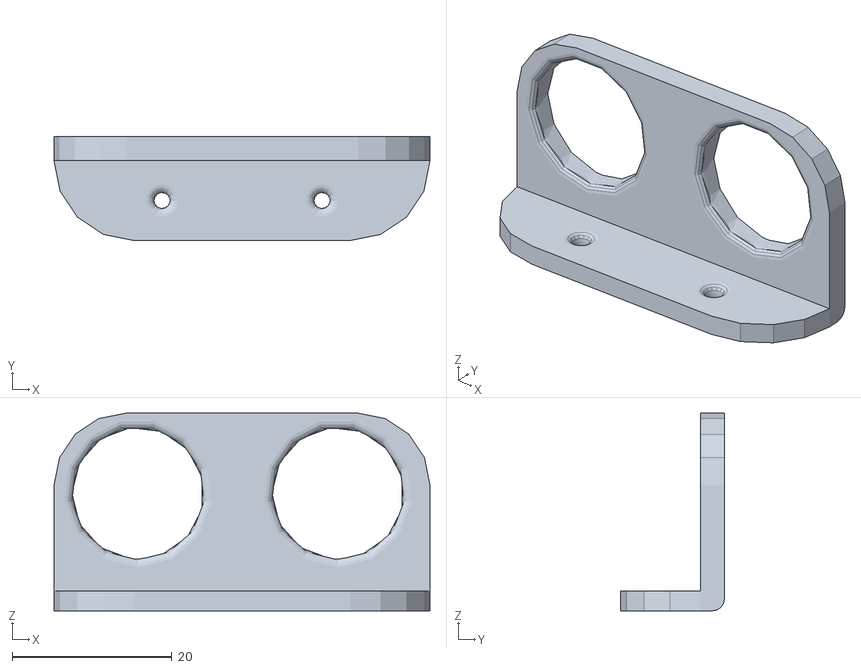
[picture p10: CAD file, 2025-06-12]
models/ultrasonido (1).stl
47.0 x 13.0 x 24.7

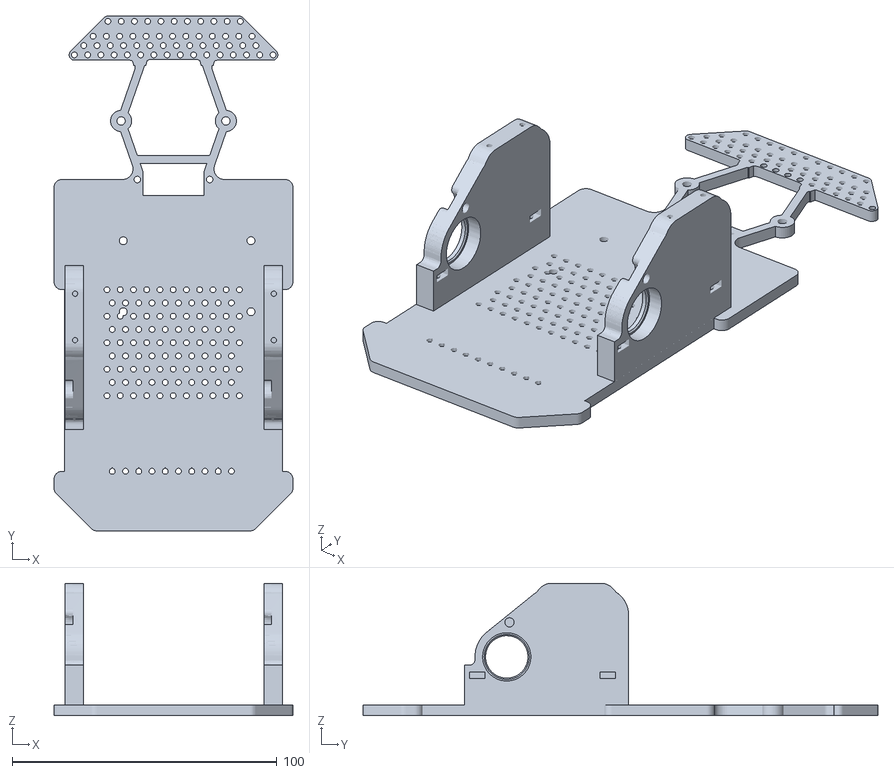
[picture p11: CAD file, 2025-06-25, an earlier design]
other/old-3d-models/Base Car V2.stl
90.2 x 194.4 x 50.0

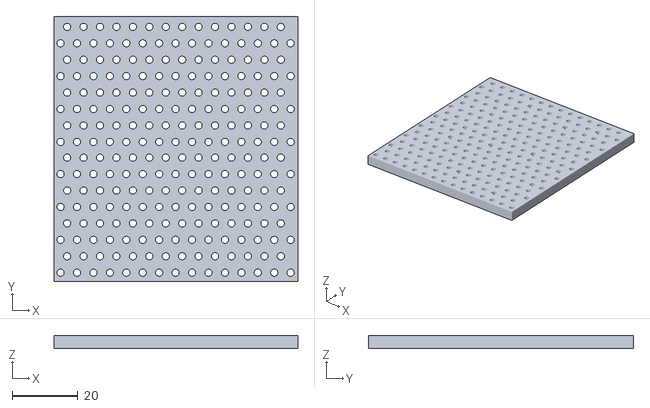
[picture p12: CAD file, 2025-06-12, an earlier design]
other/old-3d-models/Breadboard.stl
74.2 x 80.7 x 4.00

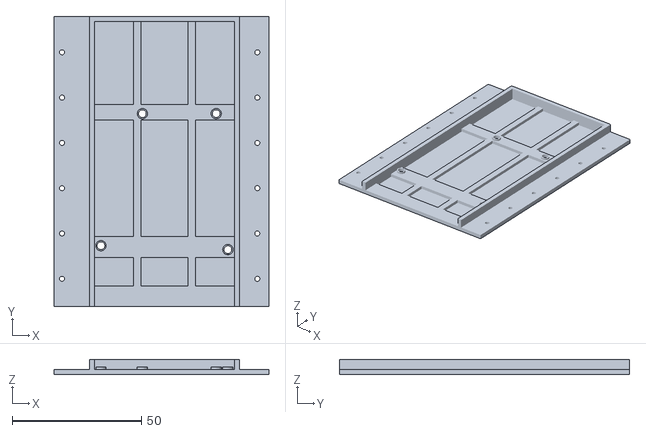
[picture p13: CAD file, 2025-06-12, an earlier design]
other/old-3d-models/Arduino Mount.stl
82.9 x 112.0 x 5.96

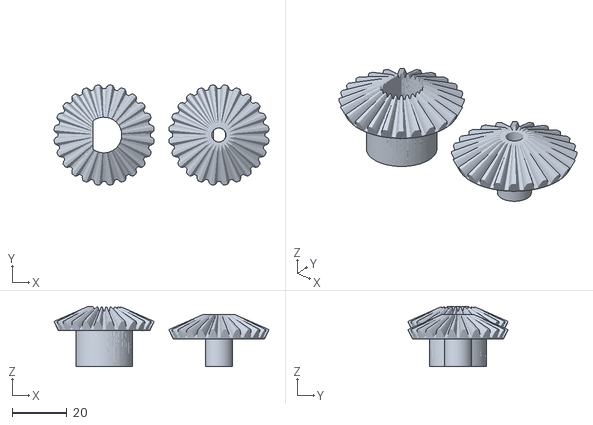
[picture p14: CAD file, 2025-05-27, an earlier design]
other/old-3d-models/Engranes Car V2.stl
78.8 x 36.7 x 22.1

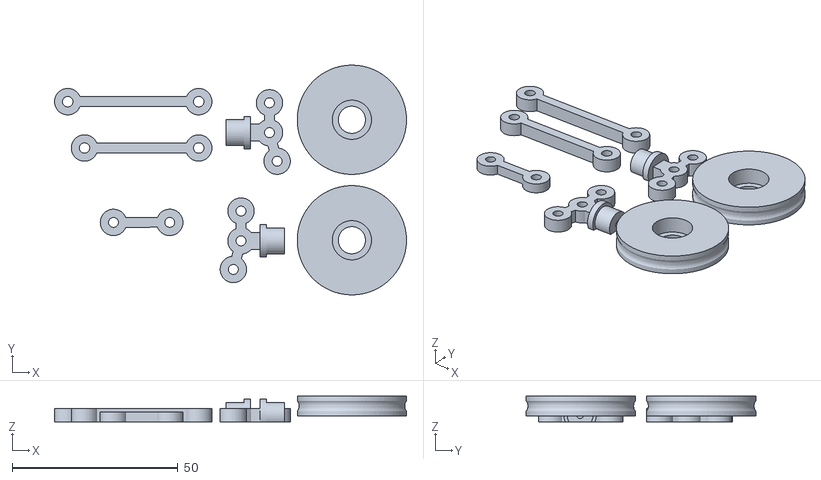
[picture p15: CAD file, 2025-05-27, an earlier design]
other/old-3d-models/Direccionales delantera.stl
106.3 x 69.4 x 7.80

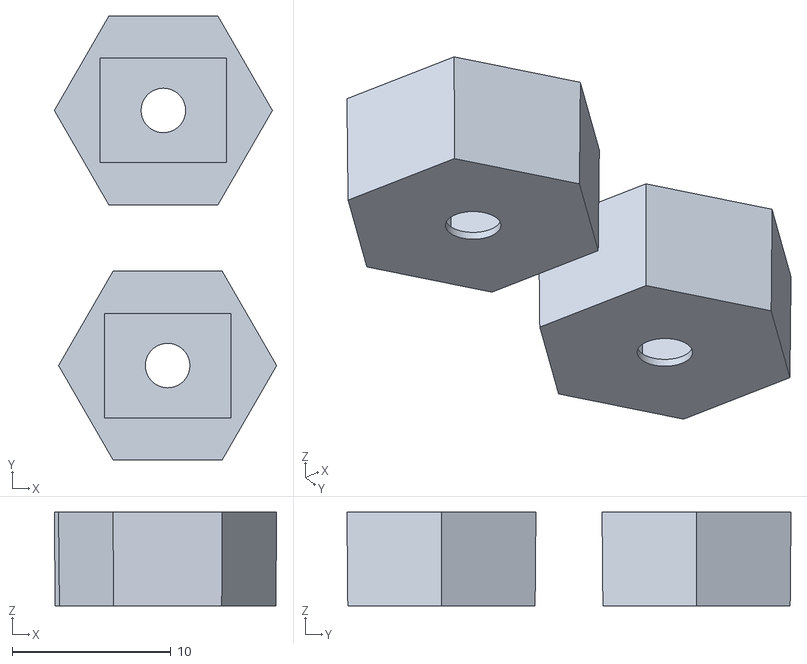
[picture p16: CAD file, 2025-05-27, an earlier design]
other/old-3d-models/Final para ejes.stl
14.0 x 28.0 x 5.90

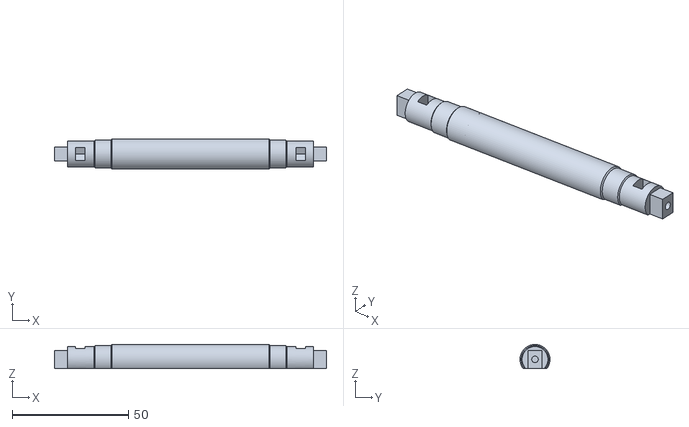
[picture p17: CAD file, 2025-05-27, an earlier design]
other/old-3d-models/Eje Car V2.stl
117.1 x 12.9 x 10.4

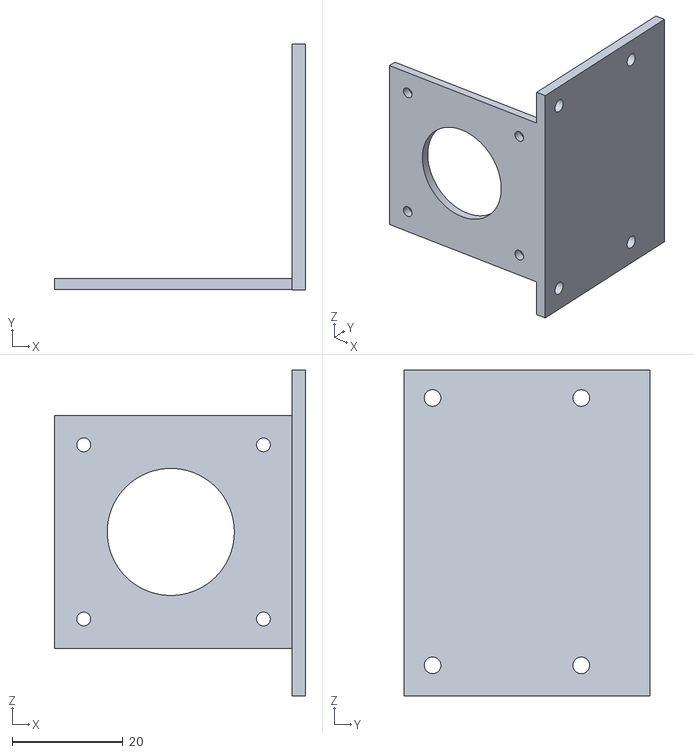
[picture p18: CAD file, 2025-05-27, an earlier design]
other/old-3d-models/Base motor Car V2.stl
45.3 x 44.3 x 58.8

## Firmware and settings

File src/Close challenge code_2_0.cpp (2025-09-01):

#include <Arduino.h>         // Librería principal de Arduino
#include <WiFi.h>            // Librería para conexión WiFi
#include <WebServer.h>
#include <Pixy2.h>           // Librería para Pixy2
#include <NewPing.h>         // Librería para sensores ultrasonicos
#include <ESP32Encoder.h>    // Librería para el manejo del encoder en ESP32
#include <ESP32Servo.h>      // Librería para el manejo de servos en ESP32


// --- Definiciones de Pixy2 ---
Pixy2 pixy;// Instancia de Pixy2

// --- Definiciones para el Motor ---
const int DIR_PIN_A = 16;                  // Pin de dirección A
const int DIR_PIN_B = 17;                  // Pin de dirección B
const int pinENB = 32;                      // Pin conectado al ENB del puente H

// --- Definiciones de Pines y Constantes para Sensores Ultrasonicos ---
#define TRIGGER_PIN_RIGHT 33                // Pin TRIGGER para el sensor ultrasonico Derecho
#define ECHO_PIN_RIGHT    25                // Pin ECHO para el sensor ultrasonico Derecho

#define TRIGGER_PIN_LEFT  27                // Pin TRIGGER para el sensor ultrasonico Izquierdo
#define ECHO_PIN_LEFT     26                // Pin ECHO para el sensor ultrasonico Izquierdo

#define TRIGGER_PIN_FRONT 13                // Pin TRIGGER para el sensor ultrasonico Frontal
#define ECHO_PIN_FRONT    14                // Pin ECHO para el sensor ultrasonico Frontal

#define TRIGGER_PIN_REAR  21                // Pin TRIGGER para el sensor ultrasonico Trasero
#define ECHO_PIN_REAR     34            // Pin ECHO para el sensor ultrasonico Trasero

Servo servo;                                // Instancia del servomotor
int servoPin = 2;                           // Pin del servomotor

int MAX_DISTANCE = 300;                     // Distancia máxima para los sensores ultrasónicos

int servoL = 115;                           // Determinar el estado basado en la posición del servomotor
int servoC = 80;                            // Determinar el estado basado en la posición del servomotor
int servoR = 50;                            // Determinar el estado basado en la posición del servomotor

int frontObject = 90;                       // Si el sensor frontal detecta a menos de esto, es hora de decidir un giro
int sense = 0;                              // Variable para el sentido de giro
int cantMuestras = 5;                       // Número de muestreos por cada sensor
int DELAY_ULTRASONICOS = 10;                // Intervalo entre pings de un mismo sensor (ms)
int wallfence = 30;                         // Estas muy cerca de la pared
int laps = 0;                               // Vueltas de cada esquina
int diameter = 66;                          // Diametro
int ppr = 1400;                             // Pulsos por revolución
int buttonState = 0;                        // Variable for reading the pushbutton status
int maximumCorrections = 0;                 // Correcciones maximas permitidas
int G = 0;
int R = 0;
unsigned long ultrasonicDisabledUntil = 1500;
int A = 0;

// Objetos NewPing para los sensores ultrasónicos
NewPing sonarRight(TRIGGER_PIN_RIGHT, ECHO_PIN_RIGHT, MAX_DISTANCE);
NewPing sonarLeft(TRIGGER_PIN_LEFT, ECHO_PIN_LEFT, MAX_DISTANCE);
NewPing sonarFront(TRIGGER_PIN_FRONT, ECHO_PIN_FRONT, MAX_DISTANCE);
NewPing sonarRear(TRIGGER_PIN_REAR, ECHO_PIN_REAR, MAX_DISTANCE);

unsigned int distanceRight, distanceLeft, distanceFront, distanceRear; // Distancia en cm

// --- Definiciones para el Encoder ---
ESP32Encoder encoder(true); // Instancia del encoder. 'true' habilita la detección de dirección por cuadratura
 // No pasamos la función de callback aquí, ya que la librería maneja el conteo.
long encoderTicks = 0;      // Variable para almacenar el conteo de ticks del encoder

// --- Variable para el estado del loop ---
String currentLoopState = "Iniciando..."; // Variable para almacenar el estado actual del loop
unsigned long lastStateChangeTime = 0;
const unsigned long STATE_CHANGE_INTERVAL = 2000; // Cambiar de estado cada 2 segundos para demostración

// --- Variables de Estado del Carro ---
enum CarState {
  START,
  WALL,
  SEARCH,
  RED,
  GREEN,
  STOPPED,
};
CarState currentState = START;

// --- Funciones de Pixy2 ---
String getSignatureColorName(int signature) {
  switch (signature) {
    case 1:
     Serial.print("Verde ");
      return "Verde";   // Asume que la firma 1 es Verde
    case 2:
     Serial.print("Rojo");
      return "Rojo";    // Asume que la firma 2 es Rojo
    // Añade más casos si tienes más firmas/colores entrenados
    default:
      return "Desconocido"; // Para cualquier otra firma
  }
}

// --- Funciones de Sensores Ultrasonicos ---

// Función para filtrar lecturas de ultrasonicos
unsigned int filtrarUltrasonicos(NewPing &sonar) {
    unsigned long sum = 0;
    unsigned int minVal = MAX_DISTANCE;
    unsigned int maxVal = 0;
    int validCount = 0;

    for (int i = 0; i < cantMuestras; i++) {
        unsigned int dist = sonar.ping_cm();

        if (dist == 0) {
            dist = MAX_DISTANCE;
        }

        sum += dist;

        if (dist < minVal) {
            minVal = dist;
        }
        if (dist > maxVal) {
            maxVal = dist;
        }
        validCount++;
        delay(DELAY_ULTRASONICOS);
    }

    if (validCount == 0) {
        return MAX_DISTANCE;
    }

    sum -= minVal;
    sum -= maxVal;

    int divisor = validCount;
    if (validCount >= 3) {
        divisor -= 2;
    }

    if (divisor == 0) return MAX_DISTANCE;

    return (unsigned int)(sum / divisor);
}

// Función para leer sensores ultrasónicos (solo lógica de lectura)
void readUltrasonicSensors() {
  distanceFront = filtrarUltrasonicos(sonarFront);
  distanceRight = filtrarUltrasonicos(sonarRight);
  distanceLeft = filtrarUltrasonicos(sonarLeft);
  distanceRear = filtrarUltrasonicos(sonarRear);

  if (distanceFront == 0) distanceFront = MAX_DISTANCE;
  if (distanceRight == 0) distanceRight = MAX_DISTANCE;
  if (distanceLeft == 0) distanceLeft = MAX_DISTANCE;
  if (distanceRear == 0) distanceRear = MAX_DISTANCE;
}


void servoRight() {   // Definimos nombre del void
  servo.write(servoR);   // Gira a la derecha
  delay(15);
}

void servoLeft() {   // Definimos nombre del void
  servo.write(servoL);   // Gira a la izquierda
  delay(15);
}

void servoCenter() {   // Definimos nombre del void
  servo.write(servoC);   // Derecho
  delay(15);
}



void setMotorDirection(bool forward) {
  if (forward) {
    digitalWrite(DIR_PIN_A, LOW);
    digitalWrite(DIR_PIN_B, HIGH);
  } else {
    digitalWrite(DIR_PIN_A, HIGH);
    digitalWrite(DIR_PIN_B, LOW);
  }
}

void stopMotor() {
  // Stops the motor
  digitalWrite(DIR_PIN_A, LOW);
  digitalWrite(DIR_PIN_B, LOW);
  digitalWrite(pinENB, LOW); // Set pinENB to LOW to completely stop the motor
}

void MotorSpeed(bool direccion, int velocidad) {

  setMotorDirection(direccion); // Set the motor direction based on the boolean parameter
  analogWrite(pinENB, velocidad); // Set the speed using digitalWrite
}

void EncoderForward(int encoderTicks) {

  encoder.clearCount();  

    while (encoder.getCount() < encoderTicks) {
  MotorSpeed(true, 200); // Move forward at speed 150
      delay(10); // Small pause to avoid blocking the main loop
  }
  stopMotor();
  encoder.clearCount(); 
  }

  void EncoderBackward(int encoderTicks) {

    encoder.clearCount(); 

    while (encoder.getCount() > encoderTicks) {
      MotorSpeed(false, 200); // Move backward at speed 150
      delay(10); // Small pause to avoid blocking the main loop
  }
  stopMotor();
  encoder.clearCount(); 
  }

void setup() {
  Serial.begin(115200);

  pixy.init(); // Inicializar la Pixy2
  Serial.println("Pixy2 inicializada.");

  pinMode(DIR_PIN_B, OUTPUT);
  pinMode(DIR_PIN_A, OUTPUT);
  pinMode(pinENB, OUTPUT); // Ensure pinENB is configured as an output

  servo.attach(servoPin, 500, 2500);

  // Configuración del encoder
  ESP32Encoder::useInternalWeakPullResistors = puType::up; // Habilita pull-up internas
  encoder.attachSingleEdge(4, 22); // Conecta los pines del encoder (ej. Canal A en GPIO 4, Canal B en GPIO 5)
                                  // ¡Verifica estos pines con tu hardware!
  encoder.clearCount();           // Reinicia el contador del encoder
  Serial.println("Encoder inicializado.");


// ...existing code...

  // Inicializar el tiempo para el cambio de estado simulado
  lastStateChangeTime = millis();

}

void loop() {

  static unsigned long straightStartTime = 0;
  unsigned long elapsed = 0;
  unsigned long tiempo = millis();

   pixy.ccc.getBlocks();

   readUltrasonicSensors();

  switch (currentState){

  case START:

  servoCenter();
  sense = 1;
  currentState = WALL;
  break;

  case WALL:

  MotorSpeed(true, 200);
  delay(2000);
  stopMotor();

  /*  if ((distanceLeft < distanceRight) && (sense == 0)) {
        sense = 2;
      } else if ((distanceRight < distanceLeft) && (sense == 0)) {
        sense = 1;
      } */

if (sense == 1){
  servoRight();
  delay(50);
  MotorSpeed(false, 200);
  delay(2000);
  servoCenter();
  EncoderForward(300);
  currentState = SEARCH;
  break;
} else if (sense == 2){
  servoLeft();
  delay(50);
  MotorSpeed(false, 200);
  delay(2000);
  servoCenter();
  EncoderForward(300);
  currentState = SEARCH;  
  break;
}


case SEARCH:

for (int i = 0; i < pixy.ccc.numBlocks; i++) {
  if (pixy.ccc.blocks[i].m_signature == 1) {
    currentState = GREEN;
    break; 
  } else if (pixy.ccc.blocks[i].m_signature == 2) {
    currentState = RED;
    break;
  } else {
    MotorSpeed(true, 200);
    delay(200);
  }
}

break;

case GREEN:


if (R == 1) {
  servoLeft();
  EncoderForward(400);
  servoRight();
  EncoderForward(900);
  servoCenter();
  EncoderForward(100);
  G = 0;
  currentState = SEARCH;
  break;
}

if ((G == 0) && (R == 0)) {
  servoLeft();
  EncoderForward(700);
  servoRight();
  EncoderForward(700);
  servoCenter();
  EncoderForward(100);
  G = 1;
  currentState = SEARCH;
  break;
} else if (G == 1) {
  MotorSpeed(true, 30);
  if (distanceFront < 20) {
    G = 0;
    currentState = WALL;
    break;
  }
}

break;

case RED:

if (G == 1) {
  servoRight();
  EncoderForward(400);
  servoLeft();
  EncoderForward(900);
  servoCenter();
  EncoderForward(100);
  G = 0;
  currentState = SEARCH;
  break;
}

  if ((R == 0) && (G == 0)) {
    servoRight();
    EncoderForward(600);
    servoLeft();
    EncoderForward(600);
    servoCenter();
    EncoderForward(100);
    R = 1;
    currentState = SEARCH;
    break;
  } else if (R == 1) {
    MotorSpeed(true, 30);
    if (distanceFront < 20) {
      R = 0;
      currentState = WALL;
      break;
    }
  }
  break;

 }
  
}

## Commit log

2025-05-27 Add files via upload
    modelo beta de el robot
    [Base Car V2.stl, Base motor Car V2.stl, Direccionales delantera.stl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]
2025-06-05 update schematic
2025-06-12 added ultrasonic sensor holder model
    [ultrasonido (1).stl]
2025-06-12 Update battery description
2025-06-12 add the missing 3d models
    [Arduino Mount.stl, Breadboard.stl]
2025-06-21 add 2.2v
2025-06-25 add new models for the vehicle
    [Direccionales Robot Chasis V4.stl, MG995.stl, Rueda v2.stl]
2025-06-25 add old 3d models
    [Arduino Mount.stl, Base Car V2.stl, Base motor Car V2.stl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]
2025-06-25 Add ToF sensor info
2025-06-25 Add ToF sensor info and update servo info
2025-06-26 putting back the ultrasonic sensor information
2025-06-27 add voltage regulator info
2025-06-27 add 3d models
    [ultrasonido (1).stl]
2025-06-27 Update to arduino uno r3
2025-07-03 add arduino mega
2025-07-04 add 3.2v
2025-07-22 add esp32 controller information
    add the new microcontroller and delte the information on the arduino mega, ad esp32 expansion board , delete the adafruit shield
2025-07-22 add volttage regulator
2025-08-21 add assembly guide
2025-08-21 Update README.md
    add how to load a code in the ESP32 from arduino ide and fix some errors
2025-09-01 add scheme final
    [DELTA Final electric diagram.fzz]
